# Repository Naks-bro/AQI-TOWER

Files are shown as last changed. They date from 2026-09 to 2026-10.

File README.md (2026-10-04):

# AQI Tower

Latest parallel engineering batch: [concrete results and one-command verification](reports/prototype_d01/batch_summary/README.md). New seal-tolerance and cabinet-joint demand tools, electrical startup/voltage/fault screens, current28-line parts register, and independent handoff audit.18 new synthetic tests pass; no seal, structure, rated circuit or physical performance approval inferred. Use the workbook's **Current combined parts** tab rather than the preserved historical parts list.

AQI Tower is a student engineering project developing a fan-and-filter air cleaner. We are preparing a small indoor prototype before investigating a larger outdoor cylindrical tower.

**Current stage:** internal engineering review. **Physical prototypes built: 0.** The design still needs mechanical and electrical release before construction.

Latest mechanical calculation: [mass and stability supplement](reports/prototype_d01/mechanical_package/MASS_STABILITY_REVIEW.md). Actual guard-hole drawings and published fan weights give a **12.61 kg partial assumed assembly**, not finished tower weight. Filters, feet, seals and controls remain unweighed; no stability approval. Includes reproducible calculations and six synthetic tests.

Latest electrical calculation: [four-page power and wiring supplement](reports/prototype_d01/electrical_package/AQI_D01_POWER_AND_WIRING_SUPPLEMENT.pdf). OEM connector-level reference, verified fan pin functions, 20 load and 36 conditional wire-drop scenarios; ten synthetic tests. Rated restart/protection, actual conductor/fuse selection and enclosure remain open. Do not energize the incomplete circuit.

Implemented ordinary-control candidate: [Opta bench drawing](reports/prototype_d01/electrical_package/AQI_D01_OPTA_BENCH_REVIEW.pdf) and [C++ firmware / source evidence](firmware/d01_opta_review/README.md).1,041 host assertions pass; default firmware also compiles for the real Opta target using official core4.6.0 / CLI1.5.1. [Reproducible board-build evidence](reports/prototype_d01/electrical_package/OPTA_BOARD_BUILD.json). Hardware testing NOT DONE. Relay outputs disabled by default. Not a protective controller or released fan wiring; PR1 remains open. Separate external-box and fuse-coordination screens included in the technical ZIP.

## See the current design

Current control-module fit: [E05 layout/input drawing](reports/prototype_d01/electrical_package/control_module/D01_E05_LID_CONTROLS_REVIEW.pdf) and [editable CAD/evidence](reports/prototype_d01/electrical_package/control_module/README.md). E04's assumed wire-space conflicts are closed by rearrangement, without shrinking reservations. Actual button stack/contact ratings, cables, mounting and rated protection remain unfinished. [Current build decision](reports/prototype_d01/electrical_package/control_module/D01_CURRENT_BUILD_DECISION.pdf) consolidates five remaining release gates. Earlier E03/E04 preserved; no drilling/wiring/build release.

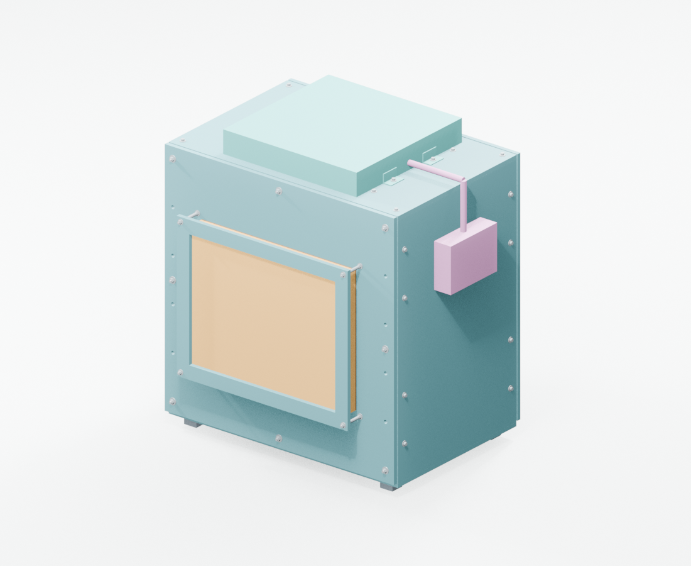
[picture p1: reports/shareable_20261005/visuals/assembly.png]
Current D01 R03M assembly rendered in Blender


*Blender rendering imported from the actual 493-object R03M CAD assembly, not a photograph. Purple parts reserve control/cable space; electrical hardware and protected cable entry are unfinished. The guard faces are solid CAD envelopes: the proposed perforations are not meshed.*

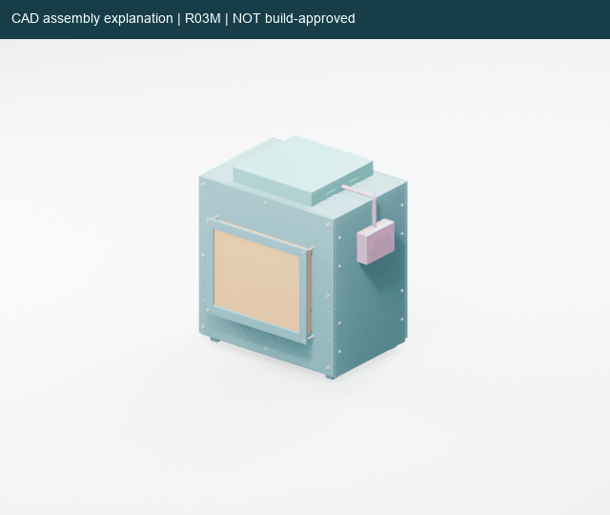
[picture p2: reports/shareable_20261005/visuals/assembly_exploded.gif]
Animated exploded view of the actual CAD assembly


*The exploded view shows how the cabinet, filters, fan plate, guards and hardware fit together. It is a design-review view; welds, threads, tolerances, strength and sealing still need assessment.*

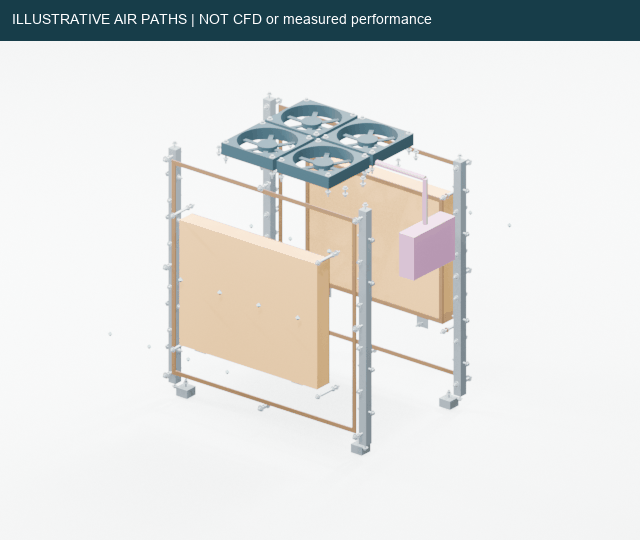
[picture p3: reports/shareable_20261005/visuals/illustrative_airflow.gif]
Illustrative air paths through a cutaway of the prototype


*Hand-authored air markers explain the intended path. This animation is NOT CFD, measured airflow or proof of cleaning. Existing historical CFD remains separately labelled in the technical report.*

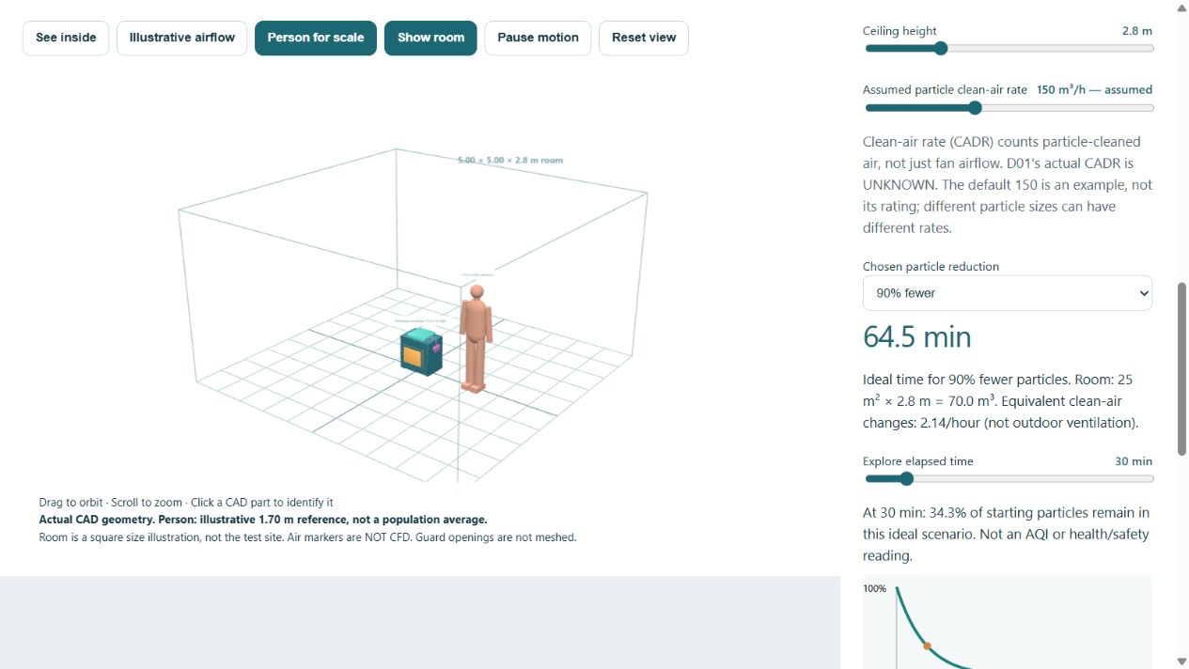
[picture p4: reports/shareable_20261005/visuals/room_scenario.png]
Adjustable room with scale person and assumed particle-cleaning scenario


*The viewer includes a 1.70 m illustrative person and adjustable room area/ceiling height, assumed particle clean-air rate, reduction goal and time. The model predicts ideal particle decay under explicit assumptions, NOT actual D01 performance or safe occupancy. Actual CADR remains unknown. See [room model basis](reports/shareable_20261005/technical/ROOM_MODEL_BASIS.md).*

## Start here

| Reader | Open first |
| --- | --- |
| Stakeholder or new team member | [8-page Executive Summary + Comprehensive Report](reports/shareable_20261005/stakeholder/AQI_TOWER_STAKEHOLDER_REPORT.pdf) or [complete stakeholder ZIP](reports/shareable_20261005/AQI_TOWER_STAKEHOLDER_BUNDLE.zip) |
| Mechanical or electrical engineer | [56-page consolidated technical handoff](reports/shareable_20261005/technical/AQI_TOWER_TECHNICAL_HANDOFF.pdf): current decisions/layout first, preserved evidence afterwards; or [complete technical ZIP](reports/shareable_20261005/AQI_TOWER_TECHNICAL_BUNDLE.zip) |
| Person budgeting the build | [Funding workbook](reports/shareable_20261005/stakeholder/STAKEHOLDER_FUNDING.xlsx); prices and stock remain unknown until quoted |
| Engineer recording decisions | [Technical review workbook](reports/shareable_20261005/technical/TECHNICAL_REVIEW.xlsx), including parts, release, pressure and hardware sheets |
| Anyone exploring the design | [Offline 3D viewer](reports/shareable_20261005/AQI_TOWER_3D_REVIEW.html), with Simple and Technical views, cutaway, part inspection and explosion controls; download and open in a WebGL browser |
| Blender user | [Editable CAD-derived presentation](reports/shareable_20261005/visuals/AQI_R03M_REVIEW.blend), not a manufacturing model |

**The shareable delivery, dated 5 October 2026, preserves IH02 / mechanical R03M evidence and adds current calculation supplements.** The technical PDF preserves the [41-page IH02 reference](reports/prototype_d01/internal_handoff_20261005/03_ENGINEERING_DRAWINGS_AND_REVIEW.pdf) after a five-page introduction, followed by the four-page E01 electrical supplement. See [delivery instructions](reports/shareable_20261005/README.md). Older R00/R01/R02 handoffs and full-size tower studies remain historical evidence; do not combine their filter, fan, wiring or drilling assumptions with this prototype. This is an engineering-review update, not a build release.

## How the first prototype works

Two removable particle filters feed a shared chamber. Four fans move air through it and out through the top guard. The filters are parallel branches, not successive filtration stages.

```mermaid
flowchart LR
    A[Room air] --> B[Filter branch 1]
    A --> C[Filter branch 2]
    B --> D[Sealed shared chamber]
    C --> D
    D --> E[Four parallel fans]
    E --> F[Guarded outlet]
```

The current concept uses four **ARCTIC P14 Max ACFAN00287A** fans and two experimental **IKEA STARKVIND 104.633.30** filter envelopes. IKEA specifies these replacement filters for its STARKVIND appliances; our custom integration has not been endorsed or validated by IKEA. The completed device has no verified HEPA classification.

An external **12 V Noctua power adapter** and OEM fan controller/hub form the electrical reference. Rated protection, isolation, enclosure and harness details remain open. Read the [electrical review](reports/prototype_d01/electrical_package/README.md) before using any schematic.

## What the evidence establishes

| Evidence | What we can say |
| --- | --- |
| CAD and drawings | An integrated assembly, exploded view, panel layouts and proposed hardware exist. Nominal fit checks do not establish manufacturing tolerances, strength or safe access. |
| Fan and pressure calculations | At an assumed 300 m³/h total, the current K1 scenario leaves about **14.32 Pa per filter**. This is conditional headroom under unverified loss assumptions, not actual flow or measured filter resistance. |
| Analysis software | Arithmetic and abstract control checks run. They do not certify hardware or establish physical performance. |
| Physical tests | No complete prototype has been built or measured in the reviewed project records. |
| Future outdoor zones | Bubble radius, removal percentage and tower spacing remain unproven. Indoor results cannot establish outdoor coverage. |

The historical sealed-filter CFD predicted approximately 1,332 m³/h for a different tower geometry and was partial/nonconverged. It does not validate D01. Carbon adsorption, solar assistance and outdoor deployment remain separate development work.

## Intended targets and room sizing

The first prototype aims to reduce airborne particles such as dust and fine smoke particles (PM2.5/PM10), not smoke gases. Actual particle capture and room reduction are unmeasured. No CO₂/CO, VOC/odour, bacteria/virus-control or health-protection performance is established. Filtration does not replace ventilation and source control.

The viewer's example 25 m² room × 2.8 m ceiling has 70 m³ of air. At **assumed**, not measured, 150 m³/h particle-cleaned flow, the ideal 90% reduction time is 64.5 min. A 90% goal in 30 min instead requires 322.4 m³/h effective clean air. Even perfect capture at the **assumed 300 m³/h airflow** screening point cannot meet that target. This calculation helps choose realistic test requirements; it does not establish a room rating. Sources and no-source/perfect-mixing limitations are in [the model basis](reports/shareable_20261005/technical/ROOM_MODEL_BASIS.md).

## What remains before building

- Confirm actual filter resistance, frame tolerances and seal behaviour.
- Finish guard strength/access, cabinet joints, stability and service details.
- Complete rated electrical protection, isolation, enclosure and wiring.
- Resolve cable dimensions requested from ARCTIC and Noctua; [enquiries are sent](docs/build/OEM_CABLE_ENQUIRIES.md).
- Agree the indoor test site and acceptance targets, obtain real quotes, then release parts and fabrication.
- Assemble, inspect, commission and measure airflow, pressure, particles, noise and power.

Internal mechanical and electrical review can proceed while manufacturer replies are pending. Use the [current release register](reports/prototype_d01/internal_handoff_20261005/REVIEW_AND_RELEASE_REGISTER.csv) to record decisions and supporting evidence.

## Repository map

| Location | Purpose |
| --- | --- |
| [Current handoff](reports/prototype_d01/internal_handoff_20261005/START_HERE.md) | Coordinated team package and current tools |
| [Mechanical package](reports/prototype_d01/mechanical_package/README.md) | Base assembly, drawings, guards, fasteners, seals and service evidence |
| [Harness study](reports/prototype_d01/mechanical_package/harness_detail/README.md) | Cable reservations and unresolved entry details |
| [Electrical package](reports/prototype_d01/electrical_package/README.md) | OEM reference chain, power budget and protective-control decisions |
| [Validation package](reports/prototype_d01/validation_package/README.md) | Physical-test preparation and corrected analysis instructions |
| [Project status](memory/project_status.md) | Dated continuation record |
| [Build starting point](docs/build/START_HERE.md) | Current and historical build context |
| [Project overview](docs/PROJECT_OVERVIEW.md) | Purpose and development phases |
| [Requirements](requirements/REQUIREMENTS.md) | Engineering requirements and assumptions |
| [Environment](docs/ENVIRONMENT.md) | Recorded computer and software setup |
| `cad/`, `cfd/`, `data/`, `results/` | Historical models, solver inputs, source data and curated results |
| `scripts/` | Geometry generation, analysis, monitoring and report builders |
| `threejs/` | Browser-based engineering viewer |

## Getting started

```bash
git clone https://github.com/Naks-bro/AQI-TOWER.git
cd AQI-TOWER
```

For documentation, start with the PDFs above. FreeCAD opens the [current native assembly](reports/prototype_d01/mechanical_package/D01_R03M_ASSEMBLY.FCStd); a [STEP export](reports/prototype_d01/mechanical_package/D01_R03M_ASSEMBLY.step) is also available. These files are for review.

Current analysis checks use Python 3 and the standard library:

```bash
python scripts/analysis/d01_validation.py
python scripts/analysis/d01_guard_bending.py
python scripts/analysis/d01_control_acceptance.py
python -m unittest discover -s scripts/analysis -p test_d01_current_filter_screen.py -v
python scripts/maintenance/check_readme_links.py
python scripts/maintenance/check_shareable_delivery.py
```

Read [tool usage](reports/prototype_d01/internal_handoff_20261005/TOOL_USAGE.md) before analysing measurements. Keep raw observations unchanged, identify calibration/source references, and label synthetic fixtures clearly. Rebuilding CAD or PDF reports requires additional software documented with the relevant builder; the small checks above do not.

For the new presentation viewer, extract either bundle and open `AQI_TOWER_3D_REVIEW.html`. No installation, server or internet is required; WebGL is required. GitHub previews do not run the HTML application. Both audiences can use the same model with different explanations.

To run the historical GEO_C engineering viewer (different geometry):

```bash
cd threejs
npm ci
npm run dev
```

OpenFOAM/ParaView workflows belong to their documented historical studies. Do not treat running an old solver case as validation of the current physical assembly.

## Contributing

Use one branch and PR for one meaningful change. Describe the problem, affected revision, checks performed and remaining limitations. Follow the [PR template](.github/pull_request_template.md), update [CHANGELOG.md](CHANGELOG.md), and update this README when the current handoff, status or onboarding workflow changes.

Keep facts, assumptions, digital predictions and physical measurements distinct. Preserve historical files and raw observations. Do not commit credentials, private correspondence, generated solver time directories, `node_modules` or local inspection screenshots. Current downloadable handoff/bundle ZIPs are intentionally tracked; redundant old report ZIPs remain local.

## What is on GitHub

Project sources, curated engineering evidence, current CAD/drawings, results, reports, workbooks, final visuals and downloadable bundles are tracked. This is not a byte-for-byte mirror of every local file. Approximately 1.75 GB of generated raw solver fields/meshes/logs, dependencies, scratch work and old recordings remain local; nothing was deleted. The [coverage inventory](reports/shareable_20261005/GITHUB_COVERAGE.csv) records excluded categories and readable sizes, including inaccessible WSL links. Existing source cases and curated CFD results remain preserved in the repository.

**AQI Tower is a working name.** The final device name has not been selected. This repository does not claim verified outdoor coverage or patentability.

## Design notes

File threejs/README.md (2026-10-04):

# AQI Tower — Engineering Viewer T3

## Current prototype presentation

The current D01 R03M prototype has a separate [offline dual-mode viewer](../reports/shareable_20261005/AQI_TOWER_3D_REVIEW.html). Download/open it locally, or extract either [shareable bundle](../reports/shareable_20261005/README.md). It uses the actual 493 CAD objects and provides Simple/Technical modes, cutaway, explosion, part inspection and explicitly illustrative air markers. A 1.70 m reference person and adjustable square room show scale; area/ceiling/assumed-CADR/time controls and reduction goals drive an ideal particle-decay chart. CADR is UNKNOWN for D01; defaults are examples. It is not a CFD solver, medical-clearance tool or manufacturing model. Test arithmetic with `node test_room_scenario.mjs` from this folder. See the [source/assumption basis](../reports/shareable_20261005/technical/ROOM_MODEL_BASIS.md).

Sources are `src/presentation.js` and `presentation.template.html`. Build its bundled JS with the existing esbuild dependency, then run `scripts/reports/build_shareable_delivery.py` using the documented ReportLab/openpyxl/Pillow/pypdf/pypdfium2 environment. The report builder also requires the existing Blender renders and current IH02 evidence. Do not treat a presentation rebuild as an engineering release.

## Historical GEO_C viewer

Interactive browser-based 3D engineering viewer for the AQI Tower GEO_C concept.
T3 adds real CFD scalar field visualization — velocity magnitude and static pressure sampled on 2-D planes from existing solved OpenFOAM cases.

**PARALLEL VISUALISATION TRACK.** This viewer is an engineering representation only. CFD field planes are post-processed from existing solved fields; they are NOT raw CFD data and are NOT physically validated. All quantities are labeled SIMULATION ONLY.

## Technology

Vite + Three.js + JavaScript ES modules. No React, no TypeScript.

## Quick start

```bash
cd threejs
npm install
npm run dev       # dev server at http://localhost:5173
npm run build     # production build → dist/
```

## File structure

```
threejs/
├── data/
│   ├── towerConfig.js          # GEO_C geometry + CFD result numbers
│   ├── engineeringStatus.js    # Status system definitions
│   ├── cases.js                # Case metadata registry (exact values from JSON sources)
│   └── particleData.js         # Phase 12B particle data, seed positions, schematic terminals
├── src/
│   ├── main.js                 # Entry point: scene, camera, controls, UI wiring, mode switching
│   ├── scene/
│   │   ├── createTower.js      # 3D geometry for all tower zones
│   │   ├── createAirflow.js    # Schematic airflow arrows
│   │   └── createParticles.js  # Particle geometry (real or schematic), filters
│   └── ui/
│       ├── infoPanel.js        # Click-to-select info panel
│       ├── layerControls.js    # Layer toggle panel
│       ├── particlePanel.js    # Particle size/outcome filter panel + Phase 12B stats
│       ├── provenancePanel.js  # Expandable data provenance panel
│       └── modeSelector.js     # ARCHITECTURE / PARTICLE / CFD SUMMARY mode tabs
├── tools/
│   ├── export_particle_trajectories.py  # Read-only pvpython export (T2)
│   └── cfd/
│       └── export_scalar_planes.py      # Read-only pvpython CFD plane export (T3)
├── public/
│   └── data/
│       ├── particleTrajectories.json    # Drop here for real particle mode (T2)
│       └── cfd/                         # CFD plane JSON files (T3, generated by export script)
├── index.html
├── vite.config.js
└── package.json
```

## Viewer modes

| Mode | Panel shown | What it shows |
|---|---|---|
| ARCHITECTURE | Layer toggles, explode slider | Tower geometry, schematic airflow, click-to-select |
| PARTICLE | Particle panel | Phase 12B seed/terminal geometry; real trajectories if exported |
| CFD SUMMARY | CFD overlay | Exact case metrics from GEO_C and CASE_M_SEALED JSON files |
| CFD FIELD | CFD field panel | Real velocity/pressure planes from solved OpenFOAM fields |

In CFD FIELD mode, the explode slider is disabled — spatial CFD planes cannot be offset from their original coordinates without becoming physically misleading.

## T3 — CFD scalar field visualization

### CFD field audit

| Case | Path | Final timestep | Status | Cells | U range | p range (Pa) |
|---|---|---|---|---|---|---|
| GEO_C | cfd/GEO_C | 926 | CONVERGED | 63,780 | 0.001–5.620 m/s | −20.43–−0.06 Pa |
| GEO_C_CONFIRM | cfd/GEO_C_CONFIRM | 926 | CONVERGED | 63,780 | 0.001–5.620 m/s | −20.43–−0.06 Pa |
| CASE_M_SEALED | cfd/FILTER_H13/CASE_M_SEALED | 5000 | PARTIALLY CONVERGED | 67,838 | 0.001–5.268 m/s | −128.92–−0.17 Pa |

GEO_C and GEO_C_CONFIRM have identical fields — confirmed deterministic reproducibility. CASE_M_SEALED has a much larger pressure range due to the H13 filter resistance (ΔP ≈ 111 Pa).

### Pressure unit interpretation

OpenFOAM `p` field has dimensions `[0 2 -2 0 0 0 0]` = m²/s² = **kinematic pressure** (p/ρ, used by incompressible RANS solvers). All values in solver units are negative (gauge relative to outlet reference).

Conversion: **P_static (Pa) = p_kinematic × ρ** where ρ = 1.20 kg/m³ (from `constant/physicalProperties`).

The export script applies this conversion and marks the field as `DERIVED FROM CFD PRESSURE FIELD`. Values are gauge pressure relative to the solver reference. Do not interpret absolute values as total pressure.

### Planes exported

| Plane ID | Normal | Position | Domain covered |
|---|---|---|---|
| `longitudinal` | y | y = 0.400 m | Full flow path from inlet to riser top |
| `filter_xsec` | x | x = 0.305 m ± 20 mm slab | Filter face / STAGE_03 cross-section |

The longitudinal plane at y = 0.400 m is the exact center of the flow domain (domain depth y ∈ [0.10, 0.70] m). This is the same plane used in the existing phase10b_visualize.py. The cross-section at x = 0.305 m corresponds to STAGE_03_mid in GEO_C metrics and the actual filter baffle position in CASE_M_SEALED.

### Export pipeline

**Dependency:** ParaView pvpython (installed in WSL)

**Tool:** Uses `OpenFOAMReader` + `vtkCellCenters` + `scipy.interpolate.griddata` (same pattern as existing `scripts/simulation/phase10b_visualize.py`).

**Grid resolution:**
- Longitudinal: 100 × 130 ≈ 13,000 grid points per field (domain: x∈[0, 0.71] m, z∈[0.14, 1.86] m)
- Filter cross-section: 65 × 75 ≈ 4,875 grid points (domain: y∈[0.09, 0.71] m, z∈[0.14, 0.88] m)

**Run from AQI-TOWER root (WSL):**
```bash
pvpython --force-offscreen-rendering threejs/tools/cfd/export_scalar_planes.py
```

**Output:** 12 JSON files + `cfd_index.json` in `threejs/public/data/cfd/`. Total size ≈ 650 KB.

### JSON format

Each export file contains:
```json
{
  "schema_version": 1,
  "case_id":        "GEO_C",
  "case_path":      "cfd/GEO_C",
  "source_timestep": "926",
  "field":          "U_MAGNITUDE",
  "field_description": "Velocity magnitude |U|",
  "derivation":     "DERIVED FROM CFD VELOCITY FIELD: |U| = sqrt(Ux² + Uy² + Uz²)",
  "units":          "m/s",
  "plane":          "longitudinal",
  "grid":           { "type": "longitudinal", "n_axis1": 100, "n_axis2": 130, ... },
  "data_min":       0.016,
  "data_max":       5.211,
  "n_valid":        10102,
  "n_total":        13000,
  "values":         [...],   // null where outside domain
  "convergence_status":  "CONVERGED",
  "validation_status":   "SIMULATION ONLY — NOT PHYSICALLY VALIDATED",
  "provenance":     { ... }
}
```

### Colormap

Six-stop turbo approximation: dark purple → cyan → green → yellow → orange → dark red. Perceptually suitable for CFD scalar visualization. Higher value = higher scalar only — no danger interpretation.

### Browser visualization limitations

- Cells are sampled on a grid; outside-domain cells are blank (null)
- Visual interpolation between grid points is for rendering only — not additional CFD resolution
- The planes are 2-D slices; no 3-D volume rendering
- Interpolation from scattered cell centers uses `scipy.griddata` linear method
- No streamline rendering (streamlines not exported; would require separate pipeline)

## Particle trajectory data

Phase 12B (`scripts/simulation/phase12b_particle_tracking.py`) does **not** store path coordinates — only terminal positions are tracked in-memory and discarded after the run. Only summary statistics exist on disk in `results/PARTICLE_CFD/particle_arrival_fractions.json`.

**Viewer behaviour:**
- On startup, the viewer attempts `fetch('./data/particleTrajectories.json')`
- If found: **REAL TRAJECTORY DATA LOADED** — actual coordinates from the export tool
- If not found: **SCHEMATIC MODE** — exact seed grid positions from script parameters; terminal positions geometry-derived using seeded PRNG (reproducible)

**Generating real trajectories:**

```bash
# WSL/Linux with ParaView pvpython
pvpython --force-offscreen-rendering threejs/tools/export_particle_trajectories.py
# Output: threejs/public/data/particleTrajectories.json (~2–3 MB)
```

The export tool replicates Phase 12B integration (equilibrium-slip Euler, dt=0.004 s, frozen CASE_M_SEALED field) and stores path waypoints every 25 steps (≈0.1 s intervals, max 60 points per particle).

**Trajectory JSON format:**
```json
{
  "meta": { "version": 1, "n_seeds": 224, "n_sizes": 4, "store_interval_steps": 25 },
  "sizes": {
    "0p3um": {
      "d_m": 3e-7,
      "particles": [
        { "outcome": "FILTER_ARRIVAL", "path": [[x0,y0,z0], [x1,y1,z1], ...] }
      ]
    }
  }
}
```
Coordinates are in Three.js space (x=flow−0.350, y=CAD_z−0.925, z=CAD_y−0.400).

## CFD streamlines

No streamline export files exist in this repository. The schematic airflow arrows in ARCHITECTURE mode follow the GEO_C flow topology but are **SCHEMATIC — NOT CFD FIELD DATA**. The provenance panel labels them clearly.

## Engineering vs schematic distinction

| Colour | Type | Meaning |
|---|---|---|
| Blue (#4a9eff) | ENGINEERING / CAD | Geometry from CAD file or physical product spec |
| Teal (#2ad4a0) | CFD SIMULATED | Value from CFD simulation result |
| Amber (#c07830) | SCHEMATIC / PROVISIONAL | Placeholder; design not frozen |
| Purple (#a050c0) | CONCEPT ONLY | No engineering basis; feasibility undecided |

## Data sources (T2)

| Data | Source file | Status |
|---|---|---|
| GEO_C flow rate, fan dP | `results/GEOMETRY_OPTIMIZATION/GEO_C/metrics.json` | Exact values in `data/cases.js` |
| CASE_M_SEALED filter ΔP, face velocity, bypass | `results/FILTER_H13/bypass_analysis_sealed.json` | Exact values in `data/cases.js` |
| Phase 12B particle counts | `results/PARTICLE_CFD/particle_arrival_fractions.json` | Exact values in `data/particleData.js` |
| Phase 12B trajectories | NOT EXPORTED | Run `tools/export_particle_trajectories.py` |
| CFD streamlines | NOT EXPORTED | No export tool exists; schematic arrows used |

## CFD summary (from exact JSON values)

All values from `results/FILTER_H13/bypass_analysis_sealed.json` and `results/PARTICLE_CFD/particle_arrival_fractions.json`. PARTIAL NON-CONVERGED RANS. Not validated on physical hardware.

| Parameter | Exact value | Source |
|---|---|---|
| Airflow (GEO_C, 926 iter) | 1496.055 m³/h | GEO_C/metrics.json |
| Airflow (CASE_M_SEALED, 5000 iter) | 1332.205 m³/h | bypass_analysis_sealed.json |
| Filter ΔP (CASE_M_SEALED) | 111.181 Pa | bypass_analysis_sealed.json |
| HEPA face velocity (mean) | 1.0525 m/s | bypass_analysis_sealed.json |
| Bypass fraction (sealed) | 9.997×10⁻¹⁰ | bypass_analysis_sealed.json |
| Particle 0.3 µm — filter arrival | 139/224 = 62.1% | particle_arrival_fractions.json |
| Particle 10 µm — filter arrival | 137/224 = 61.2% | particle_arrival_fractions.json |

**FILTER ARRIVAL ≠ FILTER CAPTURE EFFICIENCY.**
**OUTLET = 0 does NOT prove downstream capture.**

## Known limitations

- Phase 12B trajectories not exported; viewer shows schematic paths until pvpython export is run
- No real CFD streamlines exist; ARCHITECTURE mode airflow is schematic topology only
- GEO_C RANS cases did not fully converge; all CFD quantities are screening-level estimates
- No turbulent dispersion in Phase 12B particle model (equilibrium-slip Euler only)
- η(d_p) filter capture efficiency is not available — only arrival fractions are displayed

## Geometry source

GEO_C CAD parameters from `cad/parametric/PHASE8_GEOMETRY_AUDIT.json`:
- `riser_inner_x_mm`: 260 mm
- `riser_top_z_mm`: 1850 mm
- Two-step turning chamber: x=[500,590] and x=[590,690] mm

## T1 acceptance status

| Criterion | Status |
|---|---|
| Vite + Three.js + ES modules | PASS |
| GEO_C tower geometry | PASS |
| OrbitControls | PASS |
| Transparent enclosure | PASS |
| HEPA filter zone (ENGINEERING) | PASS |
| Carbon stage (SCHEMATIC/PROVISIONAL) | PASS |
| Water stage (CONCEPT) | PASS |
| Fan KVO 250 (SCHEMATIC) | PASS |
| Component selection + info panel | PASS |
| Engineering-status labels in info panel | PASS |
| Layer toggles | PASS |
| Explode view | PASS |
| Schematic airflow arrows | PASS |
| CFD summary panel | PASS |
| Dark engineering UI | PASS |
| ENGINEERING vs SCHEMATIC distinction | PASS |
| Data in towerConfig.js / engineeringStatus.js | PASS |
| No modification of cad/, cfd/, results/ | PASS |
| npm install + build succeeds | PASS |

## T3 acceptance status

| Requirement | Status |
|---|---|
| T1 preserved | PASS |
| T2 preserved | PASS |
| Existing CFD fields audited (U, p, bounds, convergence) | PASS |
| No solver rerun | PASS — export reads existing solved fields only |
| Velocity magnitude exported (|U| = sqrt(Ux²+Uy²+Uz²)) | PASS |
| Pressure exported (P = p_kin × ρ, Pa gauge) | PASS |
| Longitudinal plane (y=0.400 m) | PASS |
| Cross-section plane (x=0.305 m ± 20 mm) | PASS |
| Real CFD FIELD mode in viewer | PASS |
| Case selector (GEO_C / GEO_C_CONFIRM / CASE_M_SEALED) | PASS |
| Field selector (U magnitude / P static) | PASS |
| Plane selector (longitudinal / filter cross-section) | PASS |
| Scientific color legend (turbo colormap) | PASS |
| Units verified (U: m/s; P: Pa gauge) | PASS |
| Pressure semantics verified (kinematic × ρ=1.20 documented) | PASS |
| Provenance panel (case, path, timestep, derivation, note) | PASS |
| Convergence status displayed per case | PASS |
| No fake interpolation claims (VISUAL INTERPOLATION label) | PASS |
| Exploded view disabled in CFD_FIELD with explanation | PASS |
| Schematic airflow hidden in CFD_FIELD | PASS |
| npm run build passes | PASS — 518.21 kB in 3.39 s |
| cad/ modified | NO |
| cfd/ modified | NO |
| results/ modified | NO |
| Existing CFD outputs modified | NO |

## T2 acceptance status

| Requirement | Status |
|---|---|
| T1 fully preserved | PASS |
| Real particle data imported (fetch → real mode) | PASS |
| Schematic mode when real data unavailable | PASS |
| Diameter filter (ALL, 0.3, 1.0, 2.5, 10 µm) | PASS |
| Outcome filter (FILTER_ARRIVAL, FRAME_DEPOSIT, WALL_DEPOSIT) | PASS |
| Particle data provenance in provenance panel | PASS |
| Case metadata registry (data/cases.js, exact JSON values) | PASS |
| GEO_C metadata (exact: 1496.055 m³/h, 926 iter, CONVERGED) | PASS |
| CASE_M_SEALED metadata (exact: 1332.205 m³/h, 111.181 Pa) | PASS |
| Phase 12B particle metadata (exact counts per size/outcome) | PASS |
| Real CFD streamlines: honestly labeled NOT EXPORTED | PASS |
| No fake CFD field visualisation | PASS |
| FILTER ARRIVAL ≠ CAPTURE warning always shown | PASS |
| OUTLET = 0 ≠ downstream capture — always shown | PASS |
| SIMULATION ONLY / NOT PHYSICALLY VALIDATED labels | PASS |
| Read-only trajectory export tool provided | PASS |
| BufferGeometry + Float32Array for particle geometry | PASS |
| Mode selector (ARCHITECTURE / PARTICLE / CFD SUMMARY) | PASS |
| CFD overlay with exact case registry values | PASS |
| Expandable provenance panel | PASS |
| npm run build passes | PASS |
| cad/ modified | NO — not touched |
| cfd/ modified | NO — not touched |
| results/ modified | NO — not touched |
| Existing CFD outputs modified | NO — not touched |

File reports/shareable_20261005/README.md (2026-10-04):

# Shareable AQI Tower delivery

5 October 2026. Two audiences, one unchanged engineering basis: D01 R03M / IH02.

- stakeholder/: 8-page plain-language Executive Summary and Comprehensive Report, room-scenario/funding workbook, offline dual-mode viewer and GIFs.
- technical/: one56-page review: current build decisions/E05 control layout/E02 bench reference first, preserved earlier50-page evidence afterwards; workbook, authoritative CAD/STEP/DXFs, current tools and editable Blender presentation. Current release gates and control placement are included. Not construction release.
- The viewer now includes a1.70 m scale person, adjustable square room, area/height/assumed-CADR/time sliders and an ideal particle-decay chart. Default clean-air rate is an example, not a D01 rating. ROOM_MODEL_BASIS.md gives sources and limits.
- visuals/: actual CAD-derived renders and annotated GIFs. Colour identifies parts; air motion is illustrative, not CFD.
- GITHUB_COVERAGE.csv: excluded generated/dependency/history categories retained locally. GitHub is not an exact mirror of raw solver time folders or dependencies.

Extract either ZIP before opening its HTML. WebGL is required for 3D; PDFs and GIFs remain usable without it. The viewer is offline and includes the Three.js MIT licence. Source build tools are scripts/visualization/ and scripts/reports/build_shareable_delivery.py.

No new physical results or build approval. Exact component/filter data, mechanical/electrical release, quotations, site, fabrication and safe commissioning remain outstanding. No fabricated price or completion date. Final device name not selected.

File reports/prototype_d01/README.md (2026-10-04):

# D01 indoor demonstrator engineering package

**Latest continuation: [R01 attachment and construction details](r01/README.md).** Updated assembly, guard/cabinet/shelf fastenings, eleven revised drilling DXFs and reduced airflow screening for the guard's solid rim. R00 below is preserved; its hole drawings and airflow numbers must not be mixed with R01.

3 October 2026. R00 is a **design-review deliverable, not a fabrication, procurement or energization release**. Physical prototypes built: **0**.

Open **AQI_D01_ENGINEERING_PACKAGE.pdf** first. The first two pages explain the proposal to stakeholders; the remaining pages show the actual assembly, drawings, pressure budget, electrical connection plan, BOM and physical test procedure.

## Recommended route

Build a custom low-voltage indoor particle demonstrator before committing to the large cylindrical tower. Two opposed MERV13 filters and four top-mounted PC fans share a sealed, serviceable panel enclosure. Our work is the mechanical integration, seals, control integration, measurements and validation; it is not an off-the-shelf purifier or a claim of inventing PC-fan filtration.

This is a **recommended reduction in first-demonstrator scope**, not evidence that the larger HEPA tower is ready or that the user has approved procurement. MERV13 is not HEPA. No gas, biochar, water, solar or outdoor cleaning claim is made. The previous full-size tower route is retained, not silently replaced or released.

## Delivered files

- `D01_ASSEMBLY.FCStd` and `D01_EXPLODED.FCStd`: same assembly in native FreeCAD, 73 objects. Regenerated solid features; not a fully constrained production feature tree.
- `D01_ASSEMBLY.step`: vendor-neutral assembly geometry.
- `D01_ASSEMBLY.png` and `D01_EXPLODED.png`: renders from that CAD tessellation. Pleat markings and perforations are visual annotations; CAD filters and guard faces are envelopes. No AI concept rendering or physical photograph.
- `panel_dxf_REVIEW_ONLY/`: eight 1:1 millimetre panel/guard-outline files. No kerf compensation, guard perforation holes, unmodeled screw schedules or attachment flanges. **Do not send directly to a cutter.**
- `panel_geometry.json`: dimension and hole-coordinate data matching the generated panels.
- `D01_BOM.csv`: exact OEM reference products separated from proposed/unresolved hardware and services. No guessed prices or stock claims.
- `pressure_results.json` and `pressure_curves.csv`: reproducible screening and nine arithmetic checks; not physical results.
- `geometry_checks.json`: 435 panel/filter/support pair checks and 1,280 hardware-to-part checks; zero checked positive-volume clashes. Nuts/washers, guard-to-guard overlaps and control reservation excluded; no strength approval.

## What is fixed in this proposal

- Cabinet 550 wide x360 deep, top at580 above floor. Top guard raises height to631. Filter/retainer depth472.90 excluding studs; stud envelope reaches490. External control reservation raises width to590. No outdoor weatherproofing.
- OEM reference filter 495.3 square x44.45 deep. Sealed470 square seat aperture. Retainer550 square with475 aperture and eight5.5 clearance holes per face; minimum retainer hole centre-to-edge20. Seat edge centres minimum11; check plywood bearing and reinforcement with reviewer.
- Two235 x47.45 x9 ledges per filter, separated by20 to clear the bottom centre stud. Filter support does not rely only on gasket friction.
- Side studs: twelve M5x100; centre studs: four M5x80. Sixteen proposed M4x50 fan bolts. These lengths require delivered stack/washer/nut and thread-engagement checks; fasteners are not strength-released.
- Four P14 Max140 square x27 fans;125 mounting pitch and134.2 fan aperture from OEM drawing/template. Native fan rotors are simplified proxies.
- The Noctua NV-PS1 / included NA-AC10 / NA-FC1 / NA-FH1 chain is an OEM-documented combination, with third-party fan compatibility still to check. Four fans nominally1.4A/16.8W versus supply2A/24W; startup and auxiliary loads unmeasured.

## What was actually learned

Existing CAD/CFD and measurement scripts are reusable evidence and tools, but not one released physical machine. The full-size fan does not satisfy every assumed loaded duty point. Repeated outer-casing and closure branches advanced packaging but did not resolve component procurement or electrical release.

D01 trades HEPA and full-size flow for much simpler integration. Screening intersections are376.7,352.1 and308.7m3/h for **assumed** filter-resistance scenarios. They are not a guaranteed interval. The exact S&P filter pressure curve was not obtained; fan curve values are visually digitized. Two filters in parallel each carry half the flow; four parallel fan pressures do not add.

During this turn, review found and corrected narrow retainer ligaments, side-stud length, central-stud/inner-guard interference and lower-stud/shelf interference. Nominal clearance is not the same as a tolerance, load, seal or safety pass.

## Remaining work, specific to this assembly

1. **Obtainable parts:** resolve the P14 Max SKU/revision conflict (current PDF versus older drawing/store identity), stock and delivered manual. Checked Indian listings were out of stock. Confirm a traceable MERV13 filter with matching actual dimensions and pressure curve. India availability of S&P 990303 and the Noctua chain is UNKNOWN. A substitute requires geometry, current and pressure recalculation.
2. **Digital detailing:** complete guard flanges/fixing holes, cleat screw schedule, shelf support detail, top seam/gasket, external enclosure/gland/cable layout, washers/nuts and compression stops as appropriate. The JSON captures R00 inputs, but some construction coordinates are explicit in the generator; changing JSON alone does not update every detail.
3. **Mechanical release:** specify actual plywood, adhesive, fasteners, gasket force/landing and guard sheet; check retainer bending, joint capacity, total mass/centre of gravity, tip/slide resistance and guard reach/deflection. Then inspect dimensions and seals physically.
4. **Electrical release:** confirm actual Indian socket/approved plug adaptation, OEM connector chain, 4-fan startup current, protection and restraint. This chain does NOT implement the existing tower manual-restart/interlock requirement. Either implement a reviewed rated restart-inhibit arrangement or obtain an explicit guarded bench-only exception from the qualified reviewer; do not silently waive it. No unattended operation. Unplug before service and verify all fans stopped.
5. **Physical demonstration:** authorized purchase -> delivery -> local fabrication -> commissioning -> repeated trials with rented/paid instruments. No college lab or optional ENTC friend is assumed. Record total flow, filter pressure, watts, noise and matched room particle-decay data. Low-cost PM readings do not certify HEPA/MERV efficiency.

These are concrete remaining interfaces, not closed gates. No supplier, reviewer or workshop was contacted. No lead time, total budget or completion date is confirmed.

## Evidence and licences

Sources checked3 October2026:

- [ARCTIC manual, 2025 drawing and mounting template](https://support.arctic.de/p14-max). Dimensions140x140x27;125mm pitch. Drawing says ACFAN00287A; current spec sheet associates colour/revision differently. Do not assume an older shop listing resolves this.
- [ARCTIC P14 Max specification and chart](https://www.arctic.de/media/8a/18/01/1710507321/Spec_Sheet_P14_Max_EN.pdf). Digitization is approximate, not an OEM numeric table.
- [S&P MERV filter submittal](https://www.solerpalau-usa.com/documents/Submittal/trc-merv.pdf). Part 990303 is the MERV13 dimensional reference, not evidence of India stock or resistance. The archived file name abbreviates the part number; the full OEM part is 990303.
- [Noctua NV-PS1](https://www.noctua.at/en/products/nv-ps1), [specifications](https://www.noctua.at/en/products/nv-ps1/specifications), [NA-FH1](https://www.noctua.at/en/products/na-fh1/specifications), [NA-FC1 total-current FAQ](https://www.noctua.at/en/support/faqs/how-many-fans-can-i-connect-to-the-na-fc1-controller). OEM system ratings do not certify our assembled purifier.
- [MDComputers P14 Max listing](https://mdcomputers.in/product/arctic-p14-max-140mm-case-fan-acfan00287a): out of stock when checked, not a quotation. No claimed India-wide unavailability.
- [Tempest Brisa open-source build](https://github.com/obife29/Tempest-Brisa-Open-Source), [CC0 licence](https://github.com/obife29/Tempest-Brisa-Open-Source/blob/main/LICENSE). A DXF and licence are archived as a precedent, not reused as this CAD or treated as independent performance proof. Repository credits Maria Boavida/OMA, Shawn Santos/Ar Limpo Lisboa, Florian Festi/Boxes.py and Naomi Wu/Nukit. Credit retained; no patentability or trademark-rights claim.

Archived references are under `data/prototype_d01/sources`. `ARCTIC_P14_Max_PQ.pdf` is a failed HTML download despite its extension; it is **not evidence**. Use the valid `ARCTIC_P14_Max_Spec.pdf` chart. `MeanWell_GST60A.pdf` was screened but is not selected. Do not treat OEM documents as open-source CAD licences. The downloaded Brisa reference is the only archived construction precedent carrying the inspected CC0 licence.

## Reproduce inside this workspace

```powershell
& 'D:\Applications\FreeCAD 1.1.3\bin\python.exe' scripts/geometry/build_d01.py
& 'C:\Users\G15 5530\.cache\codex-runtimes\codex-primary-runtime\dependencies\python\python.exe' scripts/analysis/d01_pressure.py
& 'C:\Users\G15 5530\.cache\codex-runtimes\codex-primary-runtime\dependencies\python\python.exe' scripts/reports/build_d01_delivery.py
```

No new software was installed. Historical documents and models remain untouched except for navigation/status additions.

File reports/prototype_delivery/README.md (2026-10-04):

# AQI Tower stakeholder demonstration package

Created 3 October 2026. Share the PDF; open the HTML in a browser for an offline presentation. Keep PDF and HTML together so its report link works. Existing stakeholder report is preserved separately.

- `AQI_TOWER_PROTOTYPE_STAKEHOLDER_BRIEF.pdf`: six-page plain-language proposal with original functional diagrams, actual project viewer screenshot, public references, completed digital work and a funding request. No meetings page or student-led cover label.
- `PROTOTYPE_DEMO.html`: clickable layer explanations, illustrative flow animation and future network concept. No dependencies, live sensor data, new CFD or physical performance claims.
- `qa_*`: internal render/screenshot checks, not stakeholder deliverables.

The optional commercial-appliance reference demonstration is proposed for team approval. It is NOT an AQI Tower prototype or substitute proof of the custom tower. No device selected/purchased. EPA published MERV 13 precedent is not a HEPA design, India electrical approval, freely licensed third-party CAD or transferred performance result. Diagrams are our original explanation drawings, not copied manufacturer illustrations.

Build source: `scripts/reports/build_prototype_brief.py`. Run with the bundled workspace Python containing reportlab and pypdfium2. It regenerates this PDF and QA page renders; it does not modify existing models/results. Every PDF page was visually reviewed. Browser checks passed for component selection, network toggle, animation pause, absence of script errors and mobile overflow; desktop/mobile screenshots reviewed. These are presentation checks, not engineering validation.

## Short presentation script

We are developing a tower that draws air through dust filters and returns filtered air. We already have computer airflow studies, packaging models and measurement tools. We have not built or physically tested the tower yet. We are asking for support to assemble one safe indoor prototype using standard components and a local workshop, then measure what it actually does. The outdoor chain of cleaner-air zones is our future research goal, not a proven result. We can show the digital model today and, if approved, arrange a separately labelled reference-appliance demonstration while developing our own core.

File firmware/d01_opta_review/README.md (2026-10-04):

# D01 Opta ordinary-control bench candidate

**Not safety-rated. Not released for wiring, fan operation or energization.**

This is implemented C++ ordinary START/STOP/RESET logic on a specific proposed controller, Arduino Opta Lite AFX00003. It is not a replacement for the open PR1 protective circuit. No new controller has been purchased or installed. On 5 October 2026, the user authorized the isolated Arduino CLI/core installation: the default sketch compiles for the real Opta board target. Flashing and physical tests are NOT DONE.

## What the code does

- Boot, loss of the sensed source and power restoration clear RUN; held START cannot start it until released and pressed again.
- STOP has priority. A missing bench permission latches TRIP; recovery needs RESET and then a separate fresh START.
- START/RESET have an ASSUMED25 ms debounce; STOP and permission are not delayed by that debounce. Polling is nominal5 ms. A returned scan gap over ASSUMED100 ms latches an inhibit; a frozen CPU is NOT protected by this check.
- By default **all four relay commands stay LOW**, even when RUN REQUESTED is true. LEDs show requests only. The shipped sketch must never drive a fan.
- `AQI_BENCH_LAMP_OUTPUT_ENABLED=1` is solely for a reviewed, fused, low-voltage dummy-load bench. It is NOT permission to connect the tower. Output1 contact minimum-load constraints apply to the chosen dummy lamp.
- No networking, retained RUN bit, remote START or blocking wait for a USB connection.

## OEM-supported proposed input mapping

| Terminal | Arduino identifier | Proposed ordinary bench function |
|---|---|---|
| I1 | A0 | START, normally-open momentary contact |
| I2 | A1 | STOP loop, normally closed / HIGH when healthy |
| I3 | A2 | RESET, normally-open momentary contact |
| I4 | A3 | Bench permission contact; NOT a safety input |
| I5 | A4 | Unswitched12 V source-presence indication, DIGITAL mode only |
| Output1 | D0 | Disabled by default; proposed dummy-lamp contact only |

OEM terminals use their printed `+`, `-`, `I1`–`I8` and numbered output-pair labels. We do not invent COM/NO terminal identifiers. Determine actual polarity, compatible harness, source-side protection and physical terminations from the drawing and qualified bench review. Never connect12 V to an analog-mode input; OEM analog range is0–10 V, while digital range is0–24 V. A digital HIGH threshold is not precision undervoltage protection. No fan tach inputs are connected here.

Run `python scripts/analysis/test_d01_opta_host.py` from the repository or packaged engineering root with an already-installed host `g++`. It compiles the actual core and sketch against a clearly labelled GPIO shim and writes `OPTA_HOST_CHECKS.json`. This is not an Opta target build. The separate real-board build is recorded in `OPTA_BOARD_BUILD.json`; review and hardware tests are still required before bench use.

Board-build preparation: desktop tests and their Arduino shim live outside the sketch in `firmware/tests/d01_opta/`. Arduino otherwise compiles sketch-root `.cpp` files, which would bring in the test `main()` and duplicate sketch definitions. The host runner checks this layout.

DETECTED build toolchain: Arduino CLI 1.5.1 and official `arduino:mbed_opta@4.6.0`, installed only in Git-ignored `.tools/arduino/`. CLI archive SHA256 was checked against the official release checksums. No system PATH changes or hardware uploads. The default `arduino:mbed_opta:opta` target (M7 / 2 MB M7 flash split / no signing) compiled with all compiler warnings enabled: 128,464 bytes program storage and 59,232 bytes dynamic memory, no warnings reported. This proves compilation/linking, not correct operation on hardware. The dummy-lamp-enabled variant is NOT compiled or released by this check.

Reproduce on this computer: `python scripts/analysis/compile_d01_opta.py`. The script never installs or uploads; it uses the isolated existing toolchain. On another computer, install the same official versions and configure the local `.tools/arduino/arduino-cli.yaml` directories first. Evidence: [board build record](../../reports/prototype_d01/electrical_package/OPTA_BOARD_BUILD.json). Binaries/toolchain remain local, not included in the technical ZIP. Official [CLI installation instructions](https://docs.arduino.cc/arduino-cli/installation/) and [Arduino core](https://github.com/arduino/ArduinoCore-mbed) checked 5 October 2026.

## Candidate integration and unresolved protection

VERIFIED OEM: Opta Lite12–24 V supply, at12 V maximum2 W; IP20. The drawing shows70 x88.8 mm front dimensions and56.8 mm depth plus4.3 mm projection. It does not fit the current40 mm deep reservation in a normal DIN orientation. RECOMMENDATION: a separate low-voltage bench/control enclosure, not a new tower CAD branch. Hammond1554XA2GY300 x200 x120 mm is a verified enclosure candidate only; mounting plate, DIN rail, buttons, cable entries, clearances and cooling are not released. A drilled enclosure does not inherit the stock ingress rating.

The controller adds0.167 A at its maximum published12 V consumption. Fans plus controller alone demand1.567 A /18.8 W, leaving0.433 A before hub, speed-controller, input and other loads/startup. This is arithmetic, not sufficient supply proof.

The firmware cannot detect an internal fan reset with power still present, hub recovery while RUN remains true, welded contacts, a frozen MCU, safe standstill or actual guard access. Opta is ordinary control, not a safety PLC. Existing project restart/protection requirements stay OPEN and unchanged. An appropriately reviewed independent protective system must act independently of this firmware where required. Do not bridge PR1 to make this candidate run.

Primary sources checked5 October2026:

- [Arduino collective datasheet](https://docs.arduino.cc/resources/datasheets/AFX00001-AFX00002-AFX00003-datasheet.pdf), revision shown1 October2026; electrical/physical data, not complete-device approval.
- [Arduino pinout, Lite on page3](https://docs.arduino.cc/resources/pinouts/AFX00001-AFX00002-AFX00003-full-pinout.pdf). The OEM sheet is CC BY-SA4.0; linked, not republished or traced. This project's drawing is original; identifiers and technical facts are used as references.
- [Arduino official Opta mapping example](https://docs.arduino.cc/tutorials/opta/getting-started-with-interrupts). This sketch polls; it does not use that example's code.
- [Hammond exact enclosure](https://www.hammfg.com/part/1554XA2GY). Shipping weight is not installed net weight. No price or India stock claimed.

Next release evidence: accepted hazard allocation and independent protection, exact physical harness and source fault/time behavior, assessed enclosure/controls/retention, board compilation and unpowered inspection, followed by qualified dummy-load commissioning. No fan or energized live fault testing is authorized by these files.

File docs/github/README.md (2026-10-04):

# Prototype CI template

`prototype-checks.yml` is a prepared workflow template, not an active GitHub Action. It checks local README targets and current standard-library D01 analysis tools on Linux.

The authenticated GitHub credentials used for this update have repository permission but lack the `workflow` scope, so GitHub rejected creating the file under `.github/workflows/`. The template is retained here without expanding account permissions.

To activate it, a maintainer with workflow write permission can copy it to `.github/workflows/prototype-checks.yml` and commit through the normal review process. No additional Python dependencies are needed. Tests remain arithmetic and abstract software checks; they do not certify the physical unit.

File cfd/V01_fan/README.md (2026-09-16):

# V01 — Actual KVO 250 / empty Concept A tower

Status: RUN COMPLETED; PARTIAL / NON-CONVERGED, final fields at iteration 4000.

This case uses the supplied six-point Systemair KVO 250 curve, not the former fixed-300-Pa placeholder. The placeholder was never run and is preserved in archive_placeholder/.

The model predicts about 1476 m³/h, 17.33 Pa fan-static-equivalent head, and 32.46 Pa tower static-pressure difference. These are distinct pressure measures. Residual criteria are not fully met.

- Full setup: ../../docs/CFD_V01_FAN.md
- Results and limitations: ../../results/CFD_V01_FAN_RESULTS.md
- Figures and raw metrics: ../../results/CFD_V01_FAN/
- Exact input provenance: fan_implementation.json
- Mesh: copied byte-for-byte from V00; no CAD edits or new cells.
- Logs: logs/foamRun_kvo.log (initial solve, post-End cleanup crash) and logs/foamRun_kvo_continue.log (clean diagnostic continuation).
- Existing-run guards prevent automatic resets. See setup documentation before reproducing.
- The active controlDict describes continuation to iteration 4000 and preloads the locally compiled boundary library. Initial dictionaries are in logs/initial_kvo_setup/.

No filters, particles, water, solar, batteries, optimization or dashboard are included. No final fan or purification claim is made.

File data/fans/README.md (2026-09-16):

# Fan Data Requirements

## Purpose

This document defines the minimum data required from a real fan datasheet before that fan can be used in any engineering calculation or CFD model for the AQI Tower project. Nothing in this file is a product selection or a purchase recommendation.

## Why this exists

Phase 5 CFD (V00) established that the empty tower geometry produces approximately 33 Pa of flow-induced pressure loss at a placeholder inlet velocity of 1 m/s (Q = 1,512 m³/h). That number is an indicative data point, NOT the fan requirement. The actual system resistance at any real operating point depends on flow rate (Q²-scaled), the yet-unknown filter pressure drops (HEPA, prefilter, possible biochar stage), and minor losses from geometry that V00 did not model with full accuracy. A fan must be selected against a complete, documented system resistance curve — not against a single CFD number from an empty-tower placeholder run.

## Minimum required datasheet fields

Every candidate fan must provide the following before it is included in any comparison or calculation. If a field is absent, mark it MISSING and do not estimate it.

| Field | Symbol | Unit | Notes |
|---|---|---|---|
| Fan curve: at least 5 (Q, ΔP) points | — | m³/h, Pa | Static pressure rise vs. volumetric flow. Must cover shutoff (Q=0) and free-delivery (ΔP=0). |
| Maximum static pressure (shutoff head) | ΔP_max | Pa | At Q = 0. Must be sourced from the curve or datasheet, not estimated. |
| Maximum free-delivery flow | Q_max | m³/h | At ΔP = 0. |
| Rated operating point | Q_rated, ΔP_rated | m³/h, Pa | Manufacturer's stated duty point. |
| Fan type | — | — | Axial / centrifugal / mixed-flow / cross-flow. |
| Drive type | — | — | AC induction / EC (electronically commutated) / DC brushless / belt-driven. |
| Electrical supply | V_supply | V, Hz | Nominal voltage and frequency (e.g., 230 V / 50 Hz). |
| Input power at rated point | P_in | W | Electrical input. Required to estimate operating cost and power budget. |
| Efficiency at rated point | η | % | Total or static efficiency; note which. |
| Speed at rated point | n | RPM | For scaling and acoustic reference. |
| Frame / housing size | — | mm | Outer envelope: width × depth × height (or diameter). Must fit the tower cross-section. |
| Inlet / outlet duct diameter or dimensions | — | mm | For connection design. |
| Weight | — | kg | Structural load on tower. |
| Noise level | L_w or L_p | dB(A) | At rated point; note reference distance if L_p. |
| IP rating | — | — | Required for water-separation stage proximity. |
| Operating temperature range | T_min, T_max | °C | |
| Manufacturer part number and revision | — | — | Needed to verify the exact datasheet used. |
| Datasheet URL or document reference | — | — | Must be a real, retrievable source. |

## Minimum required for CFD fan BC (V01_fan)

To implement the OpenFOAM `fan` pressure-jump boundary condition the following are additionally required:

- The complete fan curve as a table of (Q, ΔP_static) pairs in SI units (m³/s, Pa), at the specific operating speed.
- If the fan speed is variable (EC motor): the curve at the speed closest to the estimated operating speed, or curves at two speeds for interpolation.
- The face area of the fan inlet or the duct cross-section where the BC will be applied (to convert patch-integrated volume flow to face velocity).

If real fan curve data are not available, the V01_fan case MUST be run with an explicit PLACEHOLDER pressure jump and documented as such. Fan curve data may NOT be invented or estimated from first principles without a physical measurement or manufacturer-provided curve.

## Current status (updated Phase 6D, 2026-09-05)

| Candidate | Data file | Evidence | Fan curve | Max ΔP (Pa) | Status |
|---|---|---|---|---|---|
| EBM-Papst G2E140-AE77-01 | `ebmpapst_G2E140_AE77-01.json` | **B** (upgraded) | NOT in operating instructions — performance datasheet needed | UNKNOWN (thermal-limit claim was misinterpretation) | **Tier 3 — re-evaluation needed** |
| EBM-Papst G2E140-AI28-A5 | `ebmpapst_G2E140_AI28-A5.json` | D | Not extracted | UNKNOWN | Tier 3 — low priority |
| EBM-Papst R2E225-RA92-09 | `ebmpapst_R2E225_RA92-09.json` | C | PDF unreadable (binary) | ~425 Pa indicative | Tier 2 — potentially suitable |
| EBM-Papst R2E225-RA92-23 | `ebmpapst_R2E225_RA92-23.json` | C | Available in PDF, not read | ~580 Pa indicative | Tier 2 — potentially suitable |
| Systemair KVO 250 | `systemair_KVO_250.json` | **A** | **6 points: 2 confirmed + 4 graph-digitized (Phase 6D)** | **~688 Pa ±20 Pa (CORRECTED — was 850 Pa)** | **Tier 1 — CFD READY WITH DIGITIZATION UNCERTAINTY** |

The KVO 250 now meets the minimum data requirements (Evidence Level A with 6 fan curve points). See `docs/FAN_DATA_GAPS.md` and `docs/FAN_CURVE_AUDIT.md` for detail.

## What to do next (priority order, Phase 6D)

1. ~~**Digitize KVO 250 fan curve points**~~ — COMPLETED Phase 6D. 6-point curve extracted via PyMuPDF.
2. **[HIGHEST PRIORITY] Confirm baffle face area** from Phase 4 FreeCAD CAD model, then implement V02_fan with real KVO 250 fan BC.
3. **Obtain ebm-papst G2E140-AE77-01 PERFORMANCE DATASHEET** (separate from operating instructions). Determines whether the G2E140 series has adequate shutoff head for this application.
4. **Find text-readable R2E225-RA92-09 fan curve.** Both PDF sources returned binary. Contact ebm-papst India or use an HTML datasheet source.
5. **Obtain multi-point HEPA ΔP curve** — contact Freudenberg or equivalent for ΔP at 3+ face velocities.
6. **Confirm tower filter face area** from Phase 4 FreeCAD CAD model.

Completed actions (Phase 6C + 6D):
- G2E140-AE77-01 operating instructions read — thermal-limit claim corrected (Phase 6C)
- KVO 250 catalog read — Evidence A, 2 confirmed fan curve points obtained (Phase 6C)
- Airflow discrepancy (R2E225-RA92-09) resolved — 705 m³/h at 50 Hz confirmed (Phase 6C)
- First HEPA H13 filter data obtained (Freudenberg, single point) (Phase 6C)
- KVO 250 fan curve expanded to 6 points via PyMuPDF vector extraction — shutoff head corrected to 688 Pa — CFD READY (Phase 6D)

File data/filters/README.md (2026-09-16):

# Filter Data Requirements

## Purpose

This directory holds structured data records for filtration components being evaluated for the AQI Tower. Filter data drives the system resistance curve — without at least one confirmed filter ΔP relationship, the operating point of any fan cannot be calculated.

## Why this exists

The AQI Tower system resistance is dominated by filter pressure drop, not by duct losses. The V00 CFD empty-tower result (~33 Pa at 1512 m³/h) is a minor term. Even a single clean H13 HEPA filter adds 80–300+ Pa depending on face velocity. Without real filter data, fan selection is speculation.

## Minimum required data fields

Every filter record must include the following before it can be used in any calculation. Mark missing fields MISSING — do not estimate them.

| Field | Symbol | Unit | Notes |
|---|---|---|---|
| Filter class / grade | — | — | EN 1822: E10–U17; ISO 29463; MERV; or equivalent |
| Dimensions (face) | W × H | mm | The flow-facing area |
| Depth | D | mm | Media pack depth |
| Rated face velocity | v_rated | m/s | Manufacturer's stated test velocity |
| Rated airflow | Q_rated | m³/h | Must be consistent with face area × face velocity |
| Initial pressure drop at rated conditions | ΔP_initial | Pa | Clean filter, sourced from manufacturer |
| Pressure drop vs. face velocity — table or curve | ΔP(v) | Pa vs m/s | At least 3 points preferred; single point acceptable if noted |
| Terminal pressure drop (replacement criterion) | ΔP_terminal | Pa | At end of service life; if stated |
| Frame material | — | — | Galvanized steel / aluminium / plastic |
| Media type | — | — | Glass fibre / synthetic; MiniPleat / deep-pleat / flat |
| Manufacturer and part number | — | — | Exact article number or model |
| Source URL or document reference | — | — | Must be a real, retrievable manufacturer source |

## Evidence levels (same as for fans)

| Level | Meaning |
|---|---|
| A | Official manufacturer datasheet with ΔP curve (multiple v points) directly obtained |
| B | Official manufacturer product page with nominal ΔP and rated conditions; single point only |
| C | Distributor or secondary source with partial data |
| D | Literature estimate only; no product-specific data |

## How filter ΔP enters the system curve

For turbulent-regime filter media (typical HEPA, prefilter):

- ΔP scales approximately **linearly** with face velocity: ΔP ∝ v. This is the viscous-dominated Darcy regime.
- Face velocity at the AQI Tower operating point: v = Q_operating / A_filter (m/s), where A_filter is the net filter face area (m²).
- Single-point linear scaling from a rated condition: ΔP_filter(Q) ≈ ΔP_rated × (Q / Q_rated), where Q_rated = v_rated × A_filter × 3600 m³/h.
- This scaling is valid only for a **clean** filter. Loaded filters may show different behaviour. If possible, use a multi-point curve.

**IMPORTANT:** This linear scaling from a single rated point is an approximation. Always note the assumed scaling when using it. It must not be cited as a measured ΔP for the AQI Tower — it is an extrapolation.

## Current status (Phase 6C, 2026-09-05)

| Product | File | Evidence | ΔP data | Status |
|---|---|---|---|---|
| Freudenberg SF13-B-0593x0593x292 (H13, galvanized steel) | `freudenberg_SF13B_593x593x292.json` | B | 300 Pa at 2.84 m/s (nominal, one point) | FIRST REAL DATA POINT — single point only |

No filter has reached Evidence Level A (full ΔP vs. v curve). The single Freudenberg data point is the first real manufacturer filter data in this project.

## Needed next actions

1. **Get full ΔP curve for the Freudenberg SF13-B (or equivalent H13 product).** Contact Freudenberg Filtration Technologies or obtain a technical datasheet with ΔP at 3+ face velocities.
2. **Determine the actual filter face area for the AQI Tower.** The tower cross-section from the FreeCAD model (Phase 4) sets the available filter area. If the filter must be smaller than the cross-section, a transition frame is needed.
3. **Obtain prefilter (G4/F7/M5 class) ΔP data.** A coarse prefilter stage will protect the HEPA from rapid loading. Its ΔP at tower operating conditions is currently entirely unknown.
4. **Obtain any data on biochar packed-bed ΔP** (Ergun equation parameters: particle diameter, void fraction, bed depth).

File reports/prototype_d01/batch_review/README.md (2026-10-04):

# Current handoff consistency and parts

`CURRENT_COMBINED_PARTS_REGISTER.csv` reconciles the current R03M indoor cabinet
and E05 external control-module candidates. It is an onboarding register, not
a purchase or construction approval. Candidate product identity does not imply
India stock, price, delivered dimensions, protective suitability or actual fit.
Do not add historical BOM quantities to this register; custom fastening uses
the controlling mechanical schedule.

`HANDOFF_CONSISTENCY.json` and `AUDIT_FINDINGS.csv` record the last executable
digital audit. Run `python scripts/maintenance/check_d01_handoff_consistency.py`
from the repository for a current read-only result. Existing bundled report
Python enables the optional PDF extraction check without installation.
`--write-results` refreshes only these audit reports; rebuild both bundles
afterward, then run the checker again without that flag.

The checker validates unchanged 493-object native tower provenance, current
E05 three-pair service evidence, default-disabled firmware and target-build
source hashes, current pressure inputs, package manifests and source copies.
Text files may be content-identical with LF/CRLF differences; this is recorded
explicitly while ZIP manifests always require exact payload bytes. Historical
IH02 pages are preserved references, not the current product/controls decision.

Passing this checker proves digital consistency only. Physical prototypes and
physical tests remain zero. Guards/structure/seals, exact connectors, protection,
commissioning and measured performance are not approved by a software audit.

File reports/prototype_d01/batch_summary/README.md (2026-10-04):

# Single-batch engineering result — 5 October 2026

Three parallel agents worked on mechanics, electrical design and handoff consistency. Root integrated their results and corrected the E05 pair-recording indentation bug. Original R03M geometry and historical IH02 evidence remain intact. **Review handoff, NOT construction or energization release. Physical prototypes: 0.**

## Concrete engineering findings

- Actual saved model: two 43 mm filter closing gaps, 36 mm sleeves, 7 mm stack offset. The new robust interval solver determines whether a fixed stop covers supplied filter/gasket/flatness intervals. In the clearly ASSUMED broad tolerance example, no fixed stop works; no seal PASS or machining setting is invented.
- Four actual eight-bolt cabinet groups now have in-plane force/moment demand calculations and equilibrium tests. Material/joint capacity, racking, withdrawal, perforated guards and full stability remain unverified.
- Electrical screen separates total source load from the fan path. Fans plus Opta yield a 1.3095× fan-current multiplier ceiling before auxiliaries, 1.2381× with an ASSUMED 0.10 A auxiliary load. These are data-acquisition thresholds, not measured inrush approval.
- An ASSUMED source-limited 2 A fault does not establish clearing of the screened 2 A fuse. No fuse/holder/PR1 selected. Hazard allocation distinguishes accessible motion and service isolation from performance interruption, preserving existing restart requirements.
- E05 assumed service volumes clear each other without reduction. Audit found the recorded service-pair list omitted a true pair and duplicated a stale self label; corrected generator now requires exactly three distinct non-self pairs. Actual intersection checks were already inside the original loop and passed.
- Current 28-line parts register replaces outdated procurement navigation, not historical evidence. Root-generated current pressure budget and freshly copied input files retain exact byte hashes. Package audit distinguishes line-ending-only equivalence from actual content differences; ZIP manifests are always strict byte checks.

## One command

From project root, using existing Python:

```
python scripts/maintenance/run_d01_release_batch.py
```

From the extracted technical bundle's `engineering/` folder:

```
python scripts/maintenance/run_d01_release_batch.py --calculations-only
```

This runs six calculation/synthetic-test programs; project-root mode also checks the complete handoff. It never installs, flashes, wires or energizes. The `--calculations-only` report is stored in BATCH_VERIFICATION.json; the independent package audit is in batch_review/HANDOFF_CONSISTENCY.json. Outcomes are digital evidence, never safety/physical approval.

Current deliverables: mechanical_package/batch_closure; electrical_package/batch_closure; batch_review/CURRENT_COMBINED_PARTS_REGISTER.csv; control_module/CURRENT_RELEASE_GATES.csv. The consolidated PDF begins with current build decisions and E05/E02 diagrams; the earlier evidence follows unchanged.

## Real blockers retained

Exact filter/frame/gasket and harness geometry; material/guard/joint/stability acceptance; actual protective function/circuit and fault coordination; real component retention, terminations/entries and thermal evaluation; agreed room/targets/instruments; authorized procurement, fabrication and qualified commissioning, followed by physical performance measurements. Numeric low-current contact suitability remains unverified because the current OEM wording is ambiguous. No prices, stock or completion dates invented.

Generated cache/backup duplicates are excluded from the delivery copy; original/local evidence and backups remain untouched. No new supplier contacts, purchases, software installations or physical results in this batch.

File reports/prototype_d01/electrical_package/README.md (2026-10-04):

# D01 electrical review E00 - 4 October 2026

**E03 body packaging:** [dimensioned external control module and editable CAD](control_module/README.md). Checked against private exact Hammond STEP, not a drilling release or completed rated panel. Closed-lid NA-FC1 access unresolved; do not run an open box. Tower CAD unchanged.

**E02 ordinary-control candidate, 5 October:** [actual-terminal bench drawing](AQI_D01_OPTA_BENCH_REVIEW.pdf), [specific hardware/fuse integration screen](OPTA_INTEGRATION_SCREEN.json), [host test results](OPTA_HOST_CHECKS.json), [implemented firmware](../../../firmware/d01_opta_review/README.md), [real target-build evidence](OPTA_BOARD_BUILD.json). Opta Lite candidate, real START/STOP/RESET C++ logic, OEM I1–I5/output1 mapping and external enclosure/fuse screen.1,041 host assertions include1,024 one-step cases; default sketch compile/link PASS for official Opta core4.6.0 with CLI1.5.1. No upload, hardware or safety qualification. Relays disabled by default. This does NOT complete protective PR1 or solve internal fan/hub recovery. Existing release gates remain. Included as separate PDF/code in current technical ZIP;50-page main PDF preserved.

**Current supplement, 5 October:** [four-page E01 power/wiring drawing](AQI_D01_POWER_AND_WIRING_SUPPLEMENT.pdf), [catalogue/conditional coordination calculation](POWER_COORDINATION.json) and [rated/reference parts](E01_RATED_PARTS.csv). Connector-level chain, official P14 Max pin functions, supply/controller/hub limits and protection coverage.20 assumed load scenarios and36 copper-drop examples; ten analytic/synthetic tests pass. No completed physical terminal schedule, fuse/wire selection or implemented protective restart. E00 PDF/ZIP preserved; E01 is included in the current50-page shareable technical handoff/ZIP.

Reproduce: `python scripts/analysis/d01_electrical_closure.py`, `python scripts/analysis/test_d01_electrical_closure.py`, `python scripts/reports/build_d01_power_closure.py` (ReportLab and pypdfium2 needed only for drawing/render). Current ARCTIC/Noctua primary source URLs and access date are in JSON. Only fan1 RPM is forwarded upstream; no four-fan protective feedback. Larger adapter alone cannot uprate the selected24W hub input. **Do not bridge unselected PR1 or energize this drawing.**

Later supplementary evidence: [protective-control candidate decision](PROTECTIVE_SELECTION_DECISION.md) and PROTECTIVE_CANDIDATE_SCREEN.json. Three OEM relays screened; none selected as a complete protective assembly. Eight reproducible checks pass. These supplements are not included in the original E00 PDF/ZIP.

Open **AQI_D01_ELECTRICAL_REVIEW.pdf**. This is the consolidated package 2 review for R03M, NOT released wiring or energization instructions.

Includes: OEM power-reference schematic; nominal and startup-sensitivity arithmetic; interface CSV; reference/unresolved BOM; enclosure/cable integration constraints; restart requirements with executable abstract tests; physical commissioning cases and three explicit electrical release blockers.

The protective module remains UNSELECTED. Hardware implementation, conductor/fuse ratings, terminal assignments, protective reliability and physical commissioning are not complete. Model PASS does not change this status. All physical tests NOT EXECUTED; prototypes 0.

The hub self-resetting protection and single upstream RPM channel prevent claiming this OEM chain is an independent four-fan protective system. Keep SATA unused and logger independent. No purchases, installations, supplier messages or publication performed.

Reproduce from repository root using Python with ReportLab:
`python scripts/analysis/d01_control_acceptance.py`
`python scripts/reports/build_d01_electrical_package.py`

Next meaningful work: finish rated protection/interface engineering and the actual filter/flow validation package, not another cosmetic CAD branch. Outdoor/public deployment remains unqualified.

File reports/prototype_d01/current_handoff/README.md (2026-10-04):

# START HERE — one current D01 review handoff

**Continued by [package1 R03M mechanical](../mechanical_package/README.md).** That assembly supersedes R02G mechanical details below; this R02G handoff is preserved as historical evidence. Use R03M panel/base/guard files and fastener lengths together. No fabrication release in either revision.

03 October 2026. **Design review only. NOT construction-ready. Physical prototypes:0.**

Open [AQI_D01_CURRENT_REVIEW_PACKAGE.pdf](AQI_D01_CURRENT_REVIEW_PACKAGE.pdf). It combines a plain-language project handoff with current pressure/electrical boundaries, three remaining build gates and10 panel drawings taken directly from the current CAD. It replaces the need to assemble an understanding from earlier revision PDFs. Historical evidence remains preserved.

[Download the current review bundle](AQI_D01_CURRENT_REVIEW_HANDOFF.zip). It preserves project-relative paths and includes current CAD, PDF, panel DXFs, inventory, checks and the three current-generation scripts. MANIFEST.json records hashes. It is not the full project history or a released fabrication pack. Required CAD/runtime dependencies are not bundled.

## Current authority

- [R02G integrated FreeCAD assembly](../r02_guards/D01_R02G_ASSEMBLY.FCStd), [STEP](../r02_guards/D01_R02G_ASSEMBLY.step): geometry authority; no assembly change in this handoff.
- [Ten panel DXFs](panel_DXF_REVIEW_ONLY/): current CAD-face extraction, mm, no kerf compensation or released tolerances/materials. Do NOT send directly for cutting. Other brackets/guards/hardware are not covered by these flat-panel files.
- [Complete CAD object inventory](CAD_PART_INVENTORY.csv):245 rows, including reservations, simplified envelopes and inherited notes. This is NOT a complete purchase list.
- [OEM references and missing items](COMPONENT_AND_MISSING_ITEMS.csv): covers unmodeled controls, missing hardware, seals and services. Combined with the inventory, this exposes omissions rather than silently treating them as finished parts.
- [Current pressure CSV](CURRENT_PRESSURE_BUDGET.csv), [calculation evidence](CURRENT_PRESSURE_BUDGET.json).
- [Whole-assembly audit](assembly_audit.json), [panel geometry](current_panels.json), [three build gates](BUILD_GATES.csv).

## What changed in this pass

DETECTED: earlier deliveries were fragmented and delta-only audits did not constitute a single whole-assembly handoff. This pass checks the complete current assembly, extracts all10 flat panels from actual BRep faces, verifies face-area times thickness against part volume, and inventories every object.29,116 modeled part pairs pass the0.05 mm3 clash threshold;774 pairs involving reservations or guard-to-guard seams are excluded. Native/STEP checks were already completed for R02G; no new physical result is claimed. The source CAD hash is recorded and unchanged.

New current-geometry pressure budget includes the350x270 mm openings and a separate reducer-path sensitivity. At300 total m3/h, each filter sees150 m3/h and the K=1 scenario leaves14.61 Pa filter allowance after assumed losses. This is a balance allowance, NOT an operating target approved by the user, actual filter resistance, performance margin or measured airflow. At400 total, the same assumptions leave negative allowance even before adding a filter. Eight arithmetic checks pass. No filter curve was invented and no old R01 flow prediction is presented as R02G performance.

## When does the preparation end?

There are three closure packages, not a commitment to one chat turn per small feature:

1. **Mechanical (assistant prepares; still OPEN):** finish guard face/corner/rivet joins, remaining cabinet/fan/M5 fastening stacks, sealing/compression details, cable housing/entry, and load/access/stability checks. Some quantities, materials and strengths are still unknown. Selected-component dimensions and qualified physical fit/review are needed before release.
2. **Electrical (assistant prepares; still OPEN):** rated protective isolation/restart arrangement, exact connectors/cables/enclosure and installation checks. The present OEM speed-control chain does NOT implement the stated protective functions. Qualified review and commissioning remain necessary, not delegated to an unconfirmed friend.
3. **Performance evidence (still OPEN):** actual filter resistance and seal behavior, then installed flow/power/noise and controlled indoor particle trials. Where manufacturers do not publish the needed data, measurements of real parts cannot be replaced with internet research. No supplier-contact task is being assigned to the user.

Gates1/2 and actual component fit govern safe construction/energization; gate3 governs what performance can be claimed. A safe test assembly may be built to discover performance only after its mechanical/electrical release, not by declaring unknown performance a safety approval. Internet/public evidence work may continue, but repeated cosmetic CAD revisions are not progress on the missing test evidence.

No exact number of days is defensible: no approved parts order, confirmed stock/delivery, fabricator/reviewer booking or test location exists. Do not confuse assistant computation time with supply, fabrication and test time. Funding should be staged for samples, confirmed parts, fabrication, review/commissioning and measurement. No prices or total cost fabricated.

## Sources / assumptions / unknowns

- FACT: indoor first test, funding but no college lab, eventual outdoor goal, no physical prototype.
- DETECTED: saved R02G geometry, public OEM references and archived curve numeric data.
- RECOMMENDATION: finish one supervised indoor particulate demonstrator; keep outdoor/weather/solar/gas/water and network work outside this first build release.
- ASSUMPTION: equal parallel fan/filter flows, full2800 rpm, density1.2 kg/m3, guard active area300x300 mm at40% open, plenum K1.5, guard K1.5 each, fan-aperture-based installation allowance K1, reducer K0.5/1/2. Added reducer loss may overlap the existing plenum allowance; none of these K values is validated. No bypass assumed. No physical uncertainty band implied.
- UNKNOWN: selected filter clean/loaded curve and frame landing, installed fan performance, seal compression/leakage, materials/strength, mass/tipping, protective electrical implementation, procurement and test outcomes.

Source references (previously accessed03 October2026): [ARCTIC numeric workbook](https://support.arctic.de/products/p14-max/techdocs/P14%20Max%20-%20PQ%20Curve%20for%20CFD.XLSX), [ARCTIC support](https://support.arctic.de/p14-max), [IKEA STARKVIND104.633.30](https://www.ikea.com/in/en/p/starkvind-filter-for-particle-removal-10463330/), [Noctua NV-PS1](https://www.noctua.at/en/products/nv-ps1), [NA-FH1](https://www.noctua.at/en/products/na-fh1/specifications), [NA-FC1 total-current FAQ](https://www.noctua.at/en/support/faqs/how-many-fans-can-i-connect-to-the-na-fc1-controller).

The IKEA part is intended by its OEM only for STARKVIND. This custom integration is experimental, not endorsed. No HEPA/MERV rating is assigned to our current assembly. ARCTIC numeric/brochure discrepancies remain unresolved; the numeric curve is not averaged with the brochure. Hardware dimensional sources are in the preserved R02H/R02G READMEs. OEM material is evidence, not an open-source manufacturing licence. The handoff ZIP does not redistribute OEM downloads.

The aqi-build-review skill drove whole-assembly verification, same-flow pressure accounting, and the explicit separation of digital work from physical release. No purchase, install, contact or public publishing occurred.

## Reproduce

```powershell
& 'D:\Applications\FreeCAD 1.1.3\bin\python.exe' scripts/geometry/audit_d01_current.py
& 'C:\Users\G15 5530\.cache\codex-runtimes\codex-primary-runtime\dependencies\python\python.exe' scripts/analysis/d01_current_pressure_budget.py
& 'C:\Users\G15 5530\.cache\codex-runtimes\codex-primary-runtime\dependencies\python\python.exe' scripts/reports/build_d01_current_handoff.py
```

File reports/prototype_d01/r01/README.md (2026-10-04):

# D01 R01 construction details

R01 continues the same D01 assembly. **Design review only; not released for fabrication, procurement or energizing.** R00 is preserved as historical evidence. Physical prototypes built: 0.

Start with `D01_R01_CONSTRUCTION_DETAILS.pdf` (five visually inspected drawing sheets). The updated native CAD is `D01_R01_ASSEMBLY.FCStd`; the neutral export is `D01_R01_ASSEMBLY.step`. The illustration comes from this CAD, not an AI concept image.

`BOM_R01.csv` consolidates the original product references and new hardware; `FASTENERS_R01.csv` gives locations and proposed sizes. The R01 ZIP includes these files and the R00 base needed to reproduce the revision. Do not treat the R00 report included for context as the latest cutting or pressure basis.

## Completed in R01

- Eight guard mounting angles with rivet holes, four shared guard bolts, washer/nut envelopes and corresponding holes through the fan plate. Actual rivets remain unselected/unmodeled.
- Thirty-two proposed M4 cabinet through-joints with matching holes in panels and cleats; eight top/base timber-fixing locations.
- Eight filter-shelf support angles with corresponding seat/ledge holes and proposed screw shafts. Flush head/countersink details await actual screws.
- Eleven revised panel-outline/drilling DXFs, replacing the R00 cutting geometry for review. Four separate shelf drawings avoid assuming front/rear/left/right hole patterns are identical.
- An external cable-routing reservation. **It is not a drilled gland hole or wiring release.**
- Revised guard resistance calculation: 10 mm solid border leaves a 300 x300 mm perforated field. At assumed40% field porosity, free area is0.036 m2 per face, versus0.04096 m2 in R00. Calculated low/middle/loaded flows are359.2 /337.1 /297.5 m3/h. These are unmeasured scenarios, not a guaranteed range or CADR.
- Conditional bracket-load arithmetic, explicitly without a material allowable or structural PASS. Do not treat its illustrative50N/2kg cases as a safety standard or validated design load.

The `aqi-build-review` procedure required the changed guard geometry to feed back into pressure screening, rather than silently retaining the higher R00 estimates.

## Checks and exclusions

`checks.json` records163 valid modeled objects,12,675 nominal pair checks with no positive-volume clashes, native reopen and STEP volume checks. R00's native assembly SHA256 is recorded and remains unchanged. `pressure_results.json` contains nine arithmetic checks; `load_screening.json` adds five checks. Nominal clearance does not establish tolerance or strength.

Excluded: cable/control reservation envelopes, inherited guard-to-guard seams, actual perforation geometry, screw threads, several heads/washers/nuts, extrusion bend fillets and rivet heads. Perforations in the rendered image are a visual annotation of the proposed pattern. Wood screw cores/pilots are layout envelopes, not verified thread engagement.

The full R00 product evidence and limitations remain in `../README.md`. No new OEM suitability, stock, price or licence claims were established this turn. No external party contacted, no software installed and no purchase made.

## Construction boundary

The new attachment geometry is prepared; these specific items remain open:

1. Exact fan/filter availability and revision, filter resistance curve and real frame/seal landing.
2. Angle and guard material/grade, bend fillets, cage seam method, rivet grip, final fastener products, joint bearing/pull-out, guard reach/deflection, mass/centre of gravity and stability.
3. Timber screw type/pilot and holding capacity, top-seam tape/product, permanent sealant and physical leakage checks. Carry from the base, not the unqualified lid or clamping frames.
4. Selected flush shelf-head geometry, remaining plywood thickness and flat filter seating; do not blindly countersink from a generic hole drawing.
5. Actual cable gland/entry that maintains guard protection, restraint and extension lengths, enclosure mounting, startup current and electrical commissioning.
6. Rated restart prevention remains missing. R01 does not implement or waive the existing manual-restart/interlock requirement. No unattended use or energization release.

Shared guard bolts require supporting both guards while dismantling, with power unplugged and rotation stopped. Actual joint/safety review may require separate retained guard attachments; no independent-access safety function is claimed.

## Reproduce

Run from project root using existing runtimes:

```powershell
& 'D:\Applications\FreeCAD 1.1.3\bin\python.exe' scripts/geometry/detail_d01_r01.py
& 'C:\Users\G15 5530\.cache\codex-runtimes\codex-primary-runtime\dependencies\python\python.exe' scripts/analysis/d01_r01_checks.py
& 'C:\Users\G15 5530\.cache\codex-runtimes\codex-primary-runtime\dependencies\python\python.exe' scripts/reports/build_d01_r01.py
```

R01 imports the saved R00 native assembly. Do not overwrite that base with another design. R01 currently uses explicit construction coordinates; it is reproducible geometry, not a fully constrained parametric production model.

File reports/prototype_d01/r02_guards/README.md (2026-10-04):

# D01 R02G — independently attached fan guards

03 October 2026. **REVIEW ONLY: not released for manufacture or energizing.** Same integrated D01 assembly, continuing R02H. Physical prototypes: **0**.

## Deliverables

- [Two-sheet guard mounting drawing](D01_R02G_GUARD_MOUNTINGS.pdf)
- [Integrated FreeCAD assembly](D01_R02G_ASSEMBLY.FCStd) / [STEP](D01_R02G_ASSEMBLY.step)
- [Guard hardware delta BOM](GUARD_DELTA_BOM.csv)
- [Checks and source hash](checks.json) / [mount coordinates](mounts.json)

## Change and reason

DETECTED: R01 through R02H used four shared bolts to attach both upper and lower guard brackets. This coupled their retention. RECOMMENDATION implemented in CAD: four bolts per guard, with separate locations. Removing one set no longer removes the other's modeled attachment. This does not establish that either guard is safe or sufficiently strong.

Outer brackets now begin at y100 and220 mm, with bolt centres y120 and240. Inner brackets retain starts40 and280, bolt centres60 and300. Both sets use x105 and445. The9 mm fan plate gets four additional4.5 mm holes. Outer side skirts get a NEW blank hole pattern at y110/130/230/250,z590; omit historical y50/70/290/310 holes. The CAD fills the historical holes to describe this new blank, NOT a physical hole-plugging instruction. Bracket names retain old identifiers; use current coordinates, not the numeric name suffix.

Proposed hardware: eight M4x20 cap screws, eight7 mm AF x5 mm nuts and sixteen12 mm OD x1 mm washers. Washer bore4.3 mm remains assumed. These replace four shared M4x25 screws, four nut envelopes and eight earlier washers; do not add both hardware sets. Nominal screw projection beyond the nut is2 mm; actual locking engagement/tolerances unverified. Material, torque and reuse limits are not released.

## Verification

245 valid objects;8,641 changed-part pair checks have no positive-volume collision above0.05 mm3. Native reopen and STEP validity/volume checks pass. R02H source hash remains unchanged. Unchanged component pairs, reservation objects and inherited guard-to-guard seams are excluded.

Sixteen tool envelope checks clear: at each of eight mounts, an assumed4 mm diameter straight driver shaft extends100 mm above the screw; an assumed12 mm OD socket extends25 mm below the lower washer with clearance for the nut. Own fastening hardware is excluded. These are space reservations, not selected tools. No handles, hands, insertion trajectory, screw extraction motion, tolerance stack or physical access test is claimed. Guard-removal motion itself has not been verified. No new airflow, leakage, strength or physical result exists.

## Sources and evidence limits

Accessed2026-10-03:

- [Accu M4x20 cap screw](https://www.accu.co.uk/metric-cap-head-screws/250243-SSC-M4-20-A4-R360):20 mm under-head length,7 mm head diameter,4 mm head height,3 mm hex drive. Used only for dimensional reference; its coating/material and availability are not selected or verified for procurement.
- [Accu M4 nut](https://www.accu.co.uk/hexagon-nylon-locking-nuts/7958-HNN-M4-A4):7 mm across flats,5 mm height,0.7 mm pitch. Simplified envelope; no modeled threads/nylon insert.
- [Easyfix large M4 washer](https://www.screwfix.com/p/easyfix-steel-large-flat-washers-m4-x-1mm-100-pack/194ft):12 mm OD and1 mm thickness; bore remains assumed.
- [HSE machinery safety guidance](https://www.hse.gov.uk/work-equipment-machinery/introduction.htm) and [maintenance guidance](https://www.hse.gov.uk/work-equipment-machinery/maintenance.htm): supporting safety principles for guarding and isolation. UK guidance is NOT an Indian conformity determination, product certification or a completed risk assessment.

## Assembly review sequence and remaining gate

Prepare revised plate and outer skirt blanks, retaining other specified panel features. Complete reviewed guard face/skirt seams and bracket rivet joints. Fit inner guard independently, then outer guard. With power disconnected and reconnection prevented, verify each set remains retained when the other is removed. Collect loose hardware; these screws/nuts are not captive. Never perform this check with fans moving. Actual tool/reach and retention checks remain to be done physically by a qualified assembler/reviewer.

Unresolved: exact rivets/grip and their strength, skirt corners/face joins, guard deflection and reach protection, captive hardware or equivalent risk reduction, root radii, plate/joint strength, protected cable entry, remaining cabinet M5 hardware, filter resistance/sealing, rated isolation and restart protection. The earlier guard perforations remain a visual annotation; CAD sheets are envelopes. New bolt penetrations require sealing assessment. No physical release, outdoor/public robustness claim or India heat qualification follows from this revision.

The next useful digital closure is guard sheet/rivet joining and remaining cabinet hardware, alongside protective electrical access/isolation design. Filter pressure and seal evidence still block a defensible performance claim.

## Reproduce

From project root:

```powershell
& 'D:\Applications\FreeCAD 1.1.3\bin\python.exe' scripts/geometry/detail_d01_independent_guards.py
& 'C:\Users\G15 5530\.cache\codex-runtimes\codex-primary-runtime\dependencies\python\python.exe' scripts/reports/build_d01_guard_report.py
```

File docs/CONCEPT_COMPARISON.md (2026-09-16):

# AQI Tower — Concept Comparison

## Assessment Boundary

**PRELIMINARY QUALITATIVE ASSESSMENT**

The scores in this document are engineering judgments used to organize the next modelling steps. They are not measurements, simulation results, predicted performance, or proof that any concept satisfies the requirements.

Scoring scale:

- **1 — Poor:** serious conceptual difficulty for this criterion.
- **2 — Weak:** important disadvantages or complexity.
- **3 — Moderate:** plausible, with meaningful unknowns.
- **4 — Good:** favorable conceptual characteristics, still unvalidated.
- **5 — Promising:** particularly useful or clear for this criterion, still unvalidated.

For **pressure-loss risk**, a higher score means lower anticipated risk or easier management; it does not predict a pressure-drop value. No total score is calculated because the project has not assigned criterion weights.

## Concepts Compared

- **Concept A — Vertical Cross-Flow:** one mainly straight path through flat treatment regions into a separate clean-air riser.
- **Concept B — Central Core:** perimeter intake and radial inward flow through annular or segmented treatment regions into a central clean-air core.
- **Concept C — Dual-Sided Intake / Central Exhaust:** two independent mirrored treatment banks feeding a shared central clean-air chimney.
- **Concept D — Radial / Multi-Plenum:** a common distribution plenum feeding multiple parallel treatment branches that recombine in a clean plenum.

## Qualitative Comparison Matrix

All scores are **ENGINEERING JUDGMENT**.

| Criterion | A: Vertical Cross-Flow | B: Central Core | C: Dual-Sided / Central Exhaust | D: Radial / Multi-Plenum |
| --- | ---: | ---: | ---: | ---: |
| Airflow simplicity | 5 | 3 | 4 | 2 |
| Expected flow-uniformity potential | 3 | 4 | 4 | 5 |
| Pressure-loss risk | 4 | 3 | 3 | 2 |
| Filtration integration | 5 | 3 | 5 | 4 |
| Maintenance | 5 | 2 | 4 | 3 |
| Manufacturability | 5 | 2 | 4 | 2 |
| Scalability | 4 | 4 | 5 | 4 |
| Electrical simplicity | 4 | 4 | 3 | 2 |
| Water-stage integration | 3 | 2 | 4 | 4 |
| Sensor integration | 4 | 3 | 5 | 5 |
| CFD suitability | 5 | 4 | 4 | 3 |
| Stakeholder explainability | 5 | 4 | 4 | 2 |

## Score Rationale

### Concept A — Vertical Cross-Flow

- **ENGINEERING JUDGMENT:** The single dominant path, flat treatment slabs, and rectangular plenums make it easiest to explain, parameterize, mesh, manufacture, and service.
- **UNKNOWN:** A compact inlet and downstream extraction region may still create poor face-velocity uniformity.
- **UNKNOWN:** The outlet turn and clean riser may add loss or recirculation.
- **UNKNOWN:** Integrating a wet stage without compromising dry media may reduce its simplicity.

### Concept B — Central Core

- **ENGINEERING JUDGMENT:** Radial inflow offers an interesting path toward broad perimeter intake and compact central extraction.
- **UNKNOWN:** Surrounding walls or obstructions may cause sector-to-sector imbalance.
- **ENGINEERING JUDGMENT:** Annular or segmented seals, drains, media supports, and core access are harder to manufacture and maintain than flat cassettes.
- **UNKNOWN:** Curved or faceted filter availability and replacement method require sourcing evidence.

### Concept C — Dual-Sided Intake / Central Exhaust

- **ENGINEERING JUDGMENT:** Mirrored flat banks combine good filtration access and scalability with a clear shared exhaust path.
- **UNKNOWN:** Unequal surroundings, loading, or sealing may produce left-right imbalance.
- **ENGINEERING JUDGMENT:** Two independent banks make instrumentation and controlled module comparisons easier, but duplicate doors, seals, and possible drains.
- **UNKNOWN:** The merge into a central chimney may cause jets, loss, or short-circuiting.

### Concept D — Radial / Multi-Plenum

- **ENGINEERING JUDGMENT:** Branch-level control and sensing make this concept attractive for modular experiments and treatment isolation.
- **UNKNOWN:** Passive flow division may be poor whenever branch resistances differ.
- **ENGINEERING JUDGMENT:** Multiple junctions, seals, controls, fans, and access paths create the highest integration burden.
- **UNKNOWN:** Balancing devices could improve distribution but also add pressure loss and maintenance.

## Criterion-by-Criterion Interpretation

| Criterion | Current interpretation | Evidence eventually required |
| --- | --- | --- |
| Airflow simplicity | A has the fewest junctions; D has the most branched topology | Flow schematic review, CFD, and physical airflow measurement |
| Flow-uniformity potential | B, C, and D offer distributed flow faces but depend on plenum and resistance balance | Face-velocity maps from CFD and experiments |
| Pressure-loss risk | A appears to require fewer bends and junctions; D has the most potential local losses | Component pressure data, system model, CFD, and pressure measurements |
| Filtration integration | Flat cassette concepts A and C appear easiest to reconfigure | Filter sourcing, seal design, stage pressure data, and service trials |
| Maintenance | A offers the clearest single-face access; B may hide inner/core parts | Mock service review and later maintenance trials |
| Manufacturability | A and C use more repeated flat parts; B and D need more complex fit-up | India-specific sourcing and fabrication review |
| Scalability | C can expand parallel banks; B can add sectors; D can add branches; A can change face area | Size, flow, transport, and cost requirements |
| Electrical simplicity | A or B can use one central fan region; D may require distributed control | Fan architecture, load budget, and fault review |
| Water-stage integration | C or D can isolate a wet bank/branch; B makes drainage most difficult | Wet-subsystem concept test and contamination review |
| Sensor integration | C and D expose bank/branch differences clearly, but need more channels | Measurement plan, sensor placement study, and calibration plan |
| CFD suitability | A is the simplest first domain; B provides the strongest topological contrast | Geometry quality and mesh-independence planning |
| Stakeholder explainability | A has the most direct airflow story; D needs the most explanation | Student/stakeholder design review |

## Candidate Selection

These selections assign modelling roles. They do not choose a final product.

### Best Baseline Concept

**Concept A — Vertical Cross-Flow**

- **ENGINEERING JUDGMENT:** It has the simplest airflow topology, flat stage regions, straightforward service access, and the clearest path to a low-detail parametric model.
- **ENGINEERING JUDGMENT:** It provides a useful reference against which later complexity can be justified.
- **UNKNOWN:** Its actual flow uniformity, pressure loss, bypass behavior, and recirculation remain unproven.

### Best Alternative

**Concept B — Central Core**

- **ENGINEERING JUDGMENT:** It is topologically different from the linear baseline because it uses perimeter intake and radial inward collection.
- **ENGINEERING JUDGMENT:** Comparing it with Concept A can reveal whether broad radial collection offers enough benefit to justify more difficult manufacture and maintenance.
- **UNKNOWN:** Sector balance, central-core loss, sealing, access, and external recirculation require simulation and testing.

### High-Risk / High-Interest Concept

**Concept D — Radial / Multi-Plenum**

- **ENGINEERING JUDGMENT:** Parallel branches could support modular treatment experiments, branch-level sensing, and isolation of an experimental wet subsystem.
- **ENGINEERING JUDGMENT:** It also has the greatest risk of flow imbalance, junction loss, controls complexity, leakage, difficult cleaning, and fabrication burden.
- **UNKNOWN:** Whether these risks can be managed without losing the modular benefit.

### Retained Comparison Concept

**Concept C — Dual-Sided Intake / Central Exhaust** remains a credible concept for later comparison. Its mirrored modular banks may be practical, but it is closer to Concept A than the radial core is, so it is not assigned the “best alternative” role for the first topology comparison.

## Major Engineering Risks Across All Concepts

1. **UNKNOWN:** The intended application and air volume are not defined, so no architecture can be sized or judged against useful airflow.
2. **UNKNOWN:** The primary pollutant and target removal performance are not defined.
3. **UNKNOWN:** Filter resistance, loading behavior, sealing, and bypass may dominate the fan operating point.
4. **UNKNOWN:** Proposed fan counts and locations may interact or operate away from a stable, efficient point.
5. **UNKNOWN:** Plenums and transitions may create uneven treatment-face velocity, recirculation, and dead zones.
6. **EXPERIMENTAL:** The water stage may add moisture carryover, biological or scaling risk, drainage burden, energy use, and maintenance without sufficient pollutant benefit.
7. **SOURCE REQUIRED:** Biochar or biomass-derived media may not treat the selected pollutant or may have inadequate capacity, pressure behavior, or durability.
8. **UNKNOWN:** Inlet/exhaust placement may cause external short-circuiting, particularly when installed near walls or outdoors.
9. **UNKNOWN:** Access, sealing, replacement, cleaning, and safe wet/electrical separation may make a concept impractical.
10. **UNKNOWN:** Size, weight, noise, weather, budget, local sourcing, power, solar contribution, and validation constraints remain open.

## CFD Questions Shared by the Candidates

1. What airflow distribution occurs through each treatment-region face?
2. Where do internal recirculation, separation, high-velocity jets, and dead zones form?
3. How much pressure loss is associated with each plenum, transition, turn, branch, and placeholder treatment region?
4. How do extraction, intake, central, distributed, and push-pull fan-zone placements alter the system flow?
5. How sensitive is flow to unequal stage resistance representing loading, manufacturing variation, or blockage?
6. Does air bypass treatment regions through gaps or unintended paths?
7. How effectively do plenums, diffusers, straighteners, baffles, and turning vanes distribute flow, and what loss do they add?
8. Do the inlet and outlet positions encourage external recirculation or short-circuiting?
9. For Concepts B–D, how evenly does flow divide among sectors, banks, or branches?
10. Which geometric parameters most strongly affect flow uniformity and pressure loss?

CFD cannot establish filter efficiency, adsorption effectiveness, water hygiene, maintenance feasibility, or real fan performance without appropriate source data and physical validation.

## Decision Gates Before a Final Architecture

- **FACT:** No concept can become a final design during Phase 3.
- **UNKNOWN:** Application, pollutant target, airflow/CADR, duty cycle, and constraint targets must be approved.
- **SOURCE REQUIRED:** Candidate fan curves and stage pressure-drop data must be obtained before a meaningful operating point can be assessed.
- **SIMULATION:** Baseline and alternative airflow domains must be compared using the same documented boundary assumptions.
- **EXPERIMENTAL:** Critical component behavior and integrated performance must be measured before performance claims.
- **ENGINEERING JUDGMENT:** A concept should advance only if its predicted airflow advantage is compatible with manufacture, safe service, and physical validation.

## First Modelling Recommendation

**ENGINEERING JUDGMENT:** Build a simple parametric airflow-region model of Concept A first, then a simplified Concept B comparison model. Use the same unknown stage-resistance placeholders and boundary-condition framework so the comparison tests topology rather than arbitrary inputs. Do not add detailed filters, fan blades, particles, water, or final dimensions at the first CAD stage.

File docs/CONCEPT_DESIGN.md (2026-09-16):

# AQI Tower — Concept Design

## Phase 3 Scope

This document explores substantially different physical and airflow architectures before detailed CAD or CFD begins. It does not select final dimensions, fans, filters, materials, treatment order, or performance values.

### Engineering Traceability Labels

- **FACT** — known from the approved project requirements or a recorded source.
- **ENGINEERING JUDGMENT** — a reasoned conceptual recommendation that has not been validated.
- **UNKNOWN** — requires a requirement decision, source, simulation, or physical test.
- **ASSUMPTION** — a temporary modelling input that must be recorded and validated before use.

Unless a statement is explicitly labelled **FACT**, no architecture or feature in this document is a confirmed design requirement.

## Known Starting Conditions

- **FACT:** The intended product is a tower-type system that moves ambient air through treatment stages and discharges treated air.
- **FACT:** The application environment is not finalized; indoor, semi-enclosed, and localized outdoor use remain possibilities.
- **FACT:** No airflow, CADR, pressure-drop, particle-removal, size, power, water, noise, or reliability target has been approved.
- **FACT:** HEPA, biochar or biomass-derived media, and a water stage are candidate concepts, not a validated treatment train.
- **ASSUMPTION:** The current team concept starts from a vertical package.
- **ASSUMPTION:** Two intake plus two exhaust fans is only an initial idea and is not treated as optimal.
- **UNKNOWN:** Which architecture best serves the eventual application and pollutant target.

## Concept A — Vertical Cross-Flow

### Name

Vertical Cross-Flow with Separate Clean-Air Riser

### Basic Idea

**ENGINEERING JUDGMENT:** Use a predominantly straight, horizontal flow path through flat, replaceable treatment cassettes. After treatment, collect the air in an isolated clean-side plenum or vertical riser and discharge it away from the intake.

### Conceptual Diagram

```text
DIRTY AIR
    |
    v
+----------+   +-------------+   +----------------+   +--------------+
|  INLET   |-->| DIRTY-AIR   |-->| INTERCHANGEABLE|-->| CLEAN-AIR    |
|  REGION  |   | PLENUM      |   | STAGE REGIONS  |   | RISER/PLENUM |
+----------+   +-------------+   +----------------+   +------+-------+
                                                               |
                                                        [FAN REGION?]
                                                               |
                                                               v
                                                        CLEAN EXHAUST
```

The stage regions are placeholders. Their order and even their inclusion remain **UNKNOWN**.

### Airflow Path

1. Ambient air enters a side or lower-side inlet.
2. A dirty-air plenum spreads the flow over the available treatment face.
3. Air crosses one or more flat, removable treatment regions.
4. A clean-side collection plenum receives the treated stream.
5. The flow turns into an isolated riser or discharge passage.
6. Air exits through a top, rear, or otherwise separated exhaust.

### Fan Location

**ENGINEERING JUDGMENT:** A clean-side extraction fan region is a useful first arrangement because it creates one main flow path and keeps the fan downstream of major particle filtration. Push-only or push-pull placements remain alternatives. Fan count and fan type are **UNKNOWN**.

### Intake Location

**ENGINEERING JUDGMENT:** A broad side or lower-side intake could expose a large flat filter area and simplify the dirty plenum. Required height, face area, guards, and weather protection are **UNKNOWN**.

### Exhaust Location

**ENGINEERING JUDGMENT:** A top or high rear exhaust separated from the inlet may reduce immediate short-circuiting. The safe separation and direction depend on the final application and must be tested.

### Filter Location

Flat cassettes could sit between the dirty and clean plenums. A prefilter, HEPA region, and adsorption region can be represented as independent removable placeholders; no sequence is selected.

### Water Stage

**UNKNOWN:** If retained, a water subsystem could occupy a separate upstream cassette or lower chamber with drainage, droplet containment, and demisting. It must not expose a dry filter or electrical region to uncontrolled moisture. A dry configuration that omits the water stage must remain possible.

### Expected Advantages

- **ENGINEERING JUDGMENT:** Simple, visible airflow path.
- **ENGINEERING JUDGMENT:** Flat filter panels may be easier to source, seal, replace, and represent in CAD.
- **ENGINEERING JUDGMENT:** Separate dirty and clean plenums support pressure measurements and staged testing.
- **ENGINEERING JUDGMENT:** Rectangular volumes should be straightforward for a first CFD model.
- **ENGINEERING JUDGMENT:** Service doors can potentially access each stage from one face.

### Potential Problems

- **UNKNOWN:** Flow may concentrate near the fan or turn, leaving parts of a filter underused.
- **UNKNOWN:** The clean-air riser and outlet turn may add pressure loss.
- **UNKNOWN:** Poor seals could allow bypass around flat cassettes.
- **UNKNOWN:** A side intake may be vulnerable to rain, impact, or obstruction in some applications.
- **UNKNOWN:** A wet stage could make the otherwise simple linear arrangement difficult to drain and isolate.

### Maintenance and Manufacturing

**ENGINEERING JUDGMENT:** Folded sheet panels or a simple frame with removable flat cassettes could make this the least complex architecture to fabricate. Clear acrylic or polycarbonate may be useful only for non-structural prototype viewing panels. A wet compartment, if used, should be a separately removable corrosion- and water-compatible module. Filter replacement, fan access, sensor taps, drains, and an isolated electrical access panel must be reachable without dismantling the whole tower.

### What CFD Must Determine

- How uniform is velocity across each treatment face?
- Does the inlet plenum need a diffuser, straightener, or baffle?
- Where do separation, recirculation, and dead zones form?
- How much loss comes from the inlet, each placeholder stage, the riser turn, and the outlet?
- Does extraction, intake, or push-pull fan placement improve the usable operating point?
- Is dirty-air or clean-air bypass likely at cassette edges?
- Is inlet-to-exhaust short-circuiting likely in the external flow field?

## Concept B — Central Core

### Name

Annular Intake with Central Clean-Air Core

### Basic Idea

**ENGINEERING JUDGMENT:** Admit air around much of the tower perimeter and draw it radially inward through concentric or segmented treatment media into a central clean-air core. Move the collected clean air vertically to an exhaust.

### Conceptual Diagram

```text
TOP VIEW

          AMBIENT AIR FROM MULTIPLE SIDES
              v       v       v
        +---------------------------+
        |  OUTER INTAKE / PLENUM    |
        |   +-------------------+   |
    --> |   | TREATMENT RING(S) |   | <--
        |   |     +-------+     |   |
    --> |   | --> | CLEAN | <-- |   | <--
        |   |     | CORE  |     |   |
        |   +-----+---+---+-----+   |
        +-------------|-------------+
                      |
                      v
              CENTRAL FAN REGION?
                      |
                      v
                 CLEAN EXHAUST
```

### Airflow Path

1. Ambient air enters around an outer perforated or segmented intake region.
2. An annular dirty-air space distributes flow around the perimeter.
3. Air moves radially inward through concentric or faceted treatment regions.
4. Treated air enters a central vertical clean-air core.
5. One or more fan regions move air along the core.
6. Air leaves through a separated upper exhaust.

### Fan Location

**ENGINEERING JUDGMENT:** A central clean-side extraction fan or stacked fan regions could create a compact pressure source. Distributed perimeter fans remain possible but would add wiring and balance questions. The arrangement is **UNKNOWN**.

### Intake Location

Intakes could cover a full circumference or selected perimeter sectors. **UNKNOWN:** A full circumference may not be suitable near walls, pedestrians, rain, or service panels.

### Exhaust Location

A vertical top exhaust aligns naturally with the central core. A side discharge would require another turn and separation from active intake sectors.

### Filter Location

Treatment media could form concentric cylinders, polygonal rings, or removable perimeter segments around the core. A prefilter could occupy the outermost accessible region; HEPA and adsorption media could occupy separate inner or outer dry segments, with their order left open. Curved HEPA or adsorption elements must not be assumed available; faceted standard cassettes may be more practical.

### Water Stage

**ENGINEERING JUDGMENT:** A wet annular stage would require a continuous or segmented collection basin below it, strong droplet containment, and a demister before any moisture-sensitive stage. Uniform spraying around a circumference is an important **UNKNOWN**. Omitting the water stage must remain an option.

### Expected Advantages

- **ENGINEERING JUDGMENT:** Large perimeter intake area may allow broad use of the tower surface.
- **ENGINEERING JUDGMENT:** Radial collection may create a compact central discharge path.
- **ENGINEERING JUDGMENT:** A central pressure source could reduce the number of separate fan stations.
- **ENGINEERING JUDGMENT:** Circumferential modularity may support adding or disabling intake sectors.

### Potential Problems

- **UNKNOWN:** Nonuniform resistance, blocked sectors, or nearby walls may cause strong circumferential imbalance.
- **UNKNOWN:** Sealing concentric or segmented media may be difficult.
- **UNKNOWN:** The inner core and rear sides of media may be hard to access.
- **UNKNOWN:** Curved parts, rings, and circular drains increase fabrication complexity.
- **UNKNOWN:** Central fan access may require removal of other components.
- **UNKNOWN:** A radial wet stage may create difficult drainage and demisting problems.

### Maintenance and Manufacturing

**ENGINEERING JUDGMENT:** A faceted polygon made from flat sheet-metal or polymer panels is more manufacturable than a fully curved shell, but the segmented seals and central-core support remain more complex than Concept A. Service doors must reach every perimeter segment, the core fan, sensors, drains, and electrical areas. Media cannot be treated as replaceable if inner segments cannot be removed safely.

### What CFD Must Determine

- How evenly does air enter around the perimeter under different surrounding obstructions?
- Does the central core draw excessively from the nearest or least-resistant sectors?
- What core size is needed to prevent high velocity and excess loss?
- Where do circumferential recirculation and axial imbalance occur?
- Can segmented media receive acceptably uniform face velocity?
- How do central versus distributed fans change flow balance?
- Does the external exhaust re-enter nearby intake sectors?
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

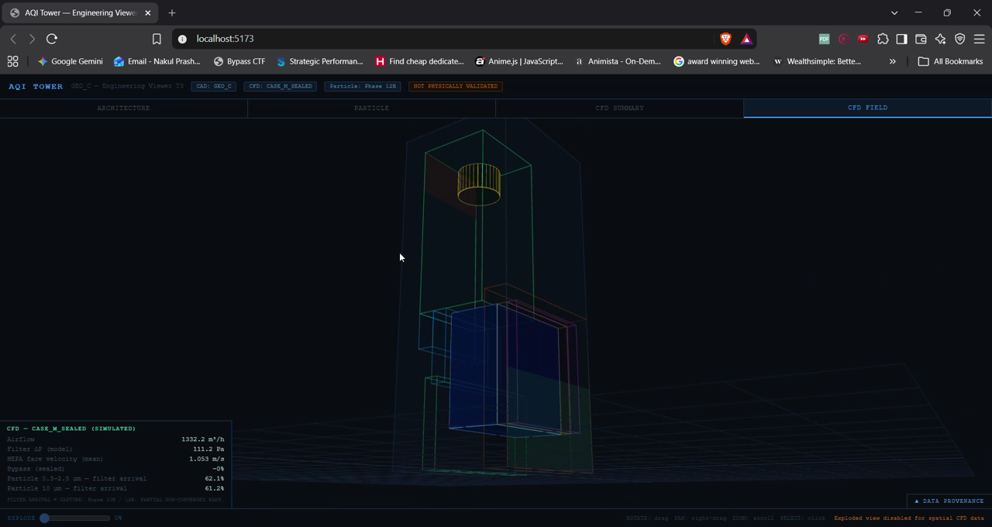
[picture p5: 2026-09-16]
reports/stakeholder_report/assets/cfd_table_a.png

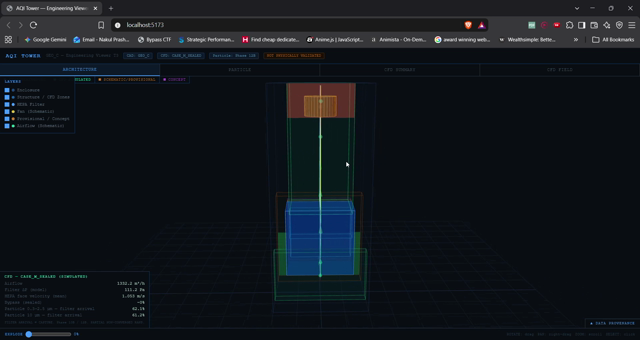
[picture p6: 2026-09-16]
reports/stakeholder_report/assets/threejs_04.png

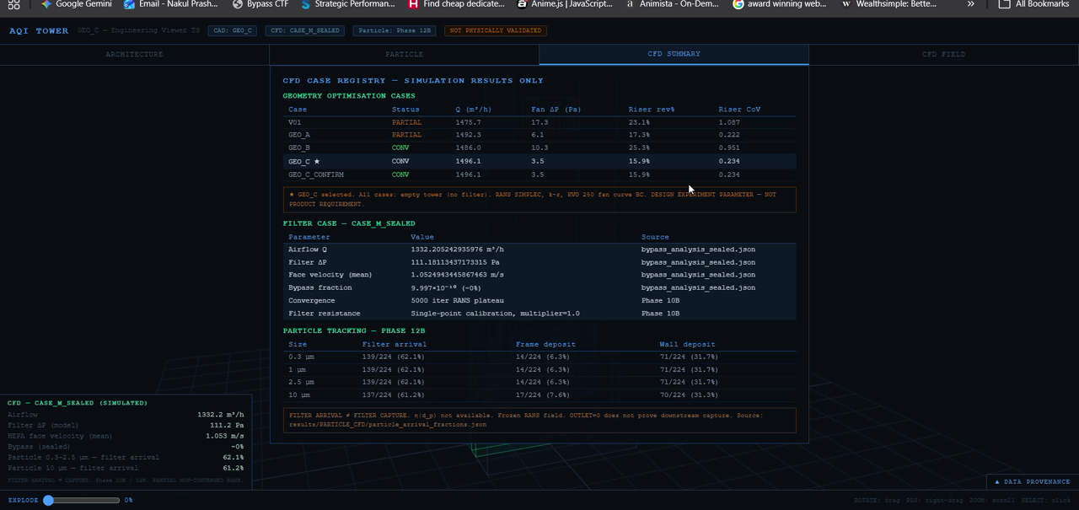
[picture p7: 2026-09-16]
reports/stakeholder_report/assets/cfd_summary_cropped.png

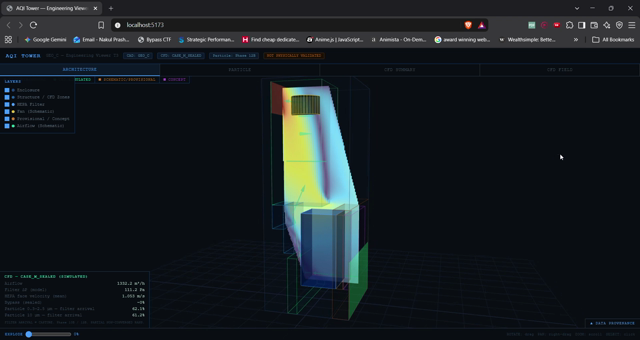
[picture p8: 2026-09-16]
reports/stakeholder_report/assets/threejs_02.png

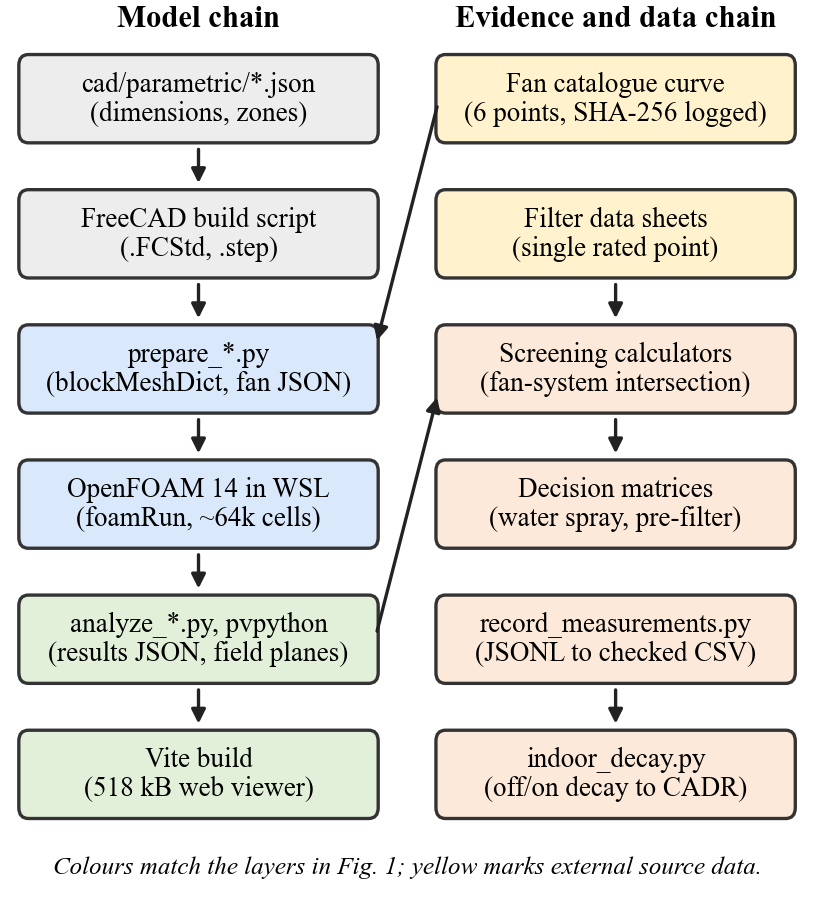
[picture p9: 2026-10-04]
docs/paper/figures/fig2_dataflow.png

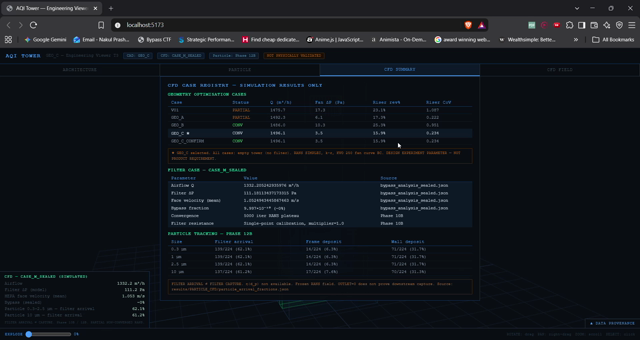
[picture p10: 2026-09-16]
reports/stakeholder_report/assets/main_07.png

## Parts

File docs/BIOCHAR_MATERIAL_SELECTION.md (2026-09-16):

# AQI Tower Phase 13 — Biochar Material Selection

**PHASE 13 — MATERIAL AND ADSORPTION EVIDENCE ONLY**  
**PHASE 13 HISTORICAL STATUS — TARGET GAS WAS NOT YET DEFINED**  
**PHASE 14 UPDATE — TARGET GAS: FORMALDEHYDE (HCHO); MATERIAL DECISION B**  
**BIOCHAR DATA STATUS: PARTIALLY READY**  
**No CFD run, CAD change, porous coefficient, or removal-performance claim**

## Purpose

The proposed carbon stage is intended for **pollutant-specific gas-phase adsorption**: selected volatile organic compounds (VOCs), organic vapors, or identified odor-causing gases. It is not a generic “AQI filter.” PM2.5 and PM10 remain particulate targets for the HEPA/prefilter system, not primary biochar targets.

An activated-carbon bed transfers gas molecules from air to a finite-capacity solid surface. Breakthrough occurs when the bed can no longer keep the downstream concentration below its selected limit. The US EPA therefore treats inlet/outlet VOC concentration, gas flow, temperature, relative humidity, pressure differential, and carbon activity as key performance indicators ([EPA carbon-adsorber guidance](https://www.epa.gov/air-emissions-monitoring-knowledge-base/monitoring-control-technique-activated-carbon-adsorber)).

### Material terms are not interchangeable

| Term | Meaning in this project | Engineering consequence |
|---|---|---|
| **BIOCHAR** | Biomass pyrolysis char without a demonstrated activation step for air adsorption | Properties can vary widely by feedstock and pyrolysis. It is not assumed to have activated-carbon pore structure or capacity. |
| **ACTIVATED CARBON** | Carbon intentionally activated by steam, CO₂, or a chemical route to develop adsorption pores | Can be an engineered granular or pelletized gas-phase medium if grade-specific data exist. |
| **ACTIVATED BIOCHAR** | Biomass-derived char given a documented post-activation or pore-development treatment | Research results apply only to that precursor and activation recipe. |
| **IMPREGNATED ADSORPTION MEDIA** | Activated carbon carrying reactive chemicals for a selected gas | Gas-specific chemistry, humidity response, heat release, compatibility, and disposal must be checked separately. |

The World Biochar Certificate defines biochar as biomass-derived porous carbon made by pyrolysis in low/no oxygen and notes that different applications require different quality characteristics ([WBC Guidelines v1.1](https://www.european-biochar.org/media/doc/2/wbc_1_1.pdf)). A peer-reviewed bamboo study likewise notes that ordinary biochar commonly has less-developed pore structure and that further physical or chemical activation produces material that is effectively activated carbon ([Rong et al., 2023](https://doi.org/10.1016/j.cej.2023.141979)).

## Candidate Materials

| Candidate | Required media distinction | Current evidence | Phase 13 role |
|---|---|---|---|
| Calgon Carbon OVC 4x8 | **C. Granulated activated carbon**, coconut shell, steam activated, non-impregnated | Manufacturer datasheet with particle specification and pressure-drop graph | **PRIMARY RESEARCH CANDIDATE** |
| Jacobi EcoSorb GX series | **C. Pelletized activated carbon**, exact grade not yet defined | Manufacturer family page; India plant/contact verified; no grade datasheet | **SECONDARY ALTERNATIVE**, conditional |
| Calgon Carbon FORMASORB | **E. Impregnated adsorption media**, coconut-shell activated carbon | Manufacturer datasheet; formaldehyde/aldehyde application; no pressure curve | **Phase 14 secondary formaldehyde-specific comparison**, conditional on exact-grade procurement and test evidence |
| SWP700 softwood-pellet biochar | **BIOCHAR**, no post-activation reported | Peer-reviewed benzene experiment | Research comparator only |
| RH550 rice-husk biochar | **A. Raw/research biochar**, no post-activation reported | Peer-reviewed MEK experiment | Research comparator only |
| R850 rice-husk activated carbon | **D. Activated biochar / biomass-derived activated carbon**, CO₂ activated | Peer-reviewed 16-VOC humidity experiment | Research comparator only |
| Bamboo BPGC | **D. Activated/modified biochar**, KOH-assisted catalytic graphitization | Peer-reviewed VOC and humidity results | Advanced research option, not procurement-ready |

## Pollutant Targets

**PHASE 14 SUPERSEDING DECISION: TARGET GAS — FORMALDEHYDE (HCHO / CH₂O, CAS 50-00-0).**

The Phase 13 statement that the target was not yet defined is retained as historical context. Phase 14 independently compared six candidates and froze HCHO. See [`PHASE14_FORMALDEHYDE_TARGET.md`](PHASE14_FORMALDEHYDE_TARGET.md) for concentrations, breakthrough definitions, safety, measurement, and experiment requirements.

The system requirement must name a compound or controlled mixture before adsorption performance can be designed. “VOC” is a class, not a single adsorbate. Evidence for benzene cannot be transferred to formaldehyde, MEK, H₂S, NO₂, ozone, or another gas.

Candidate target families for requirements work are:

- Non-polar organic vapors such as toluene or similar solvent vapors, for which non-impregnated microporous activated carbon may be relevant.
- Polar/small organic gases such as formaldehyde, which ordinary activated carbon may adsorb poorly and which can require specialized impregnated media. The EPA specifically identifies formaldehyde and methanol among compounds for which ordinary activated carbon can be less effective ([EPA Carbon Adsorbers chapter](https://www.epa.gov/sites/default/files/2018-10/documents/final_carbonadsorberschapter_7thedition.pdf)).
- Identified odor gases such as H₂S, mercaptans, or amines, which often require pollutant-specific impregnated or catalytic media rather than generic GAC.

NOx, SOx, CO, and ozone are not assigned to the carbon stage without species-specific evidence and an explicit requirement.

## Material Properties

| Candidate | Precursor and process | Surface area | Particle form | Bulk density | Pore information |
|---|---|---:|---|---:|---|
| OVC 4x8 | Coconut shell; high-temperature steam activation | NOT AVAILABLE | 4x8 US mesh, nominal range bounded by 4.75 and 2.36 mm screens | NOT AVAILABLE | High surface area/fine pores stated; no numeric distribution |
| FORMASORB | Coconut shell; steam activation plus impregnation | 1150 m²/g typical | 4x8 or 6x12 mesh | 600 kg/m³ typical | Numeric distribution NOT AVAILABLE |
| EcoSorb GX | Exact precursor/process NOT AVAILABLE | NOT AVAILABLE | Extruded pellet; diameter NOT AVAILABLE | NOT AVAILABLE | NOT AVAILABLE |
| SWP700 | Softwood pellets; pyrolysis at 700 °C | NOT AVAILABLE in accessible record | Final bed form NOT AVAILABLE | NOT AVAILABLE | NOT AVAILABLE |
| RH550 | Rice husk; pyrolysis at 550 °C | NOT AVAILABLE in accessible record | NOT AVAILABLE | NOT AVAILABLE | NOT AVAILABLE |
| R850 | Rice husk; carbonization + CO₂ activation at 850 °C | Numeric value NOT AVAILABLE in accessible record | NOT AVAILABLE | NOT AVAILABLE | Study identifies the highest surface/micropore area among its three samples |
| Bamboo BPGC | Bamboo; KOH-promoted nickel-catalyzed graphitization | 2181 m²/g | NOT AVAILABLE | NOT AVAILABLE | Micro-mesoporous; O/C = 0.038 |

Sources: [OVC 4x8 datasheet](https://www.calgoncarbon.com/app/uploads/DS-OVC4x815-EIN-E2.pdf), [FORMASORB datasheet](https://www.calgoncarbon.com/app/uploads/FORMASORB.pdf), [Jacobi product families](https://www.jacobi.net/products/), and the peer-reviewed papers recorded below.

## Adsorption Evidence

### Manufacturer/product evidence

- **OVC 4x8:** Calgon Carbon identifies it for vapor-phase VOC and odor removal and specifies carbon-tetrachloride activity of at least 60 wt%. That activity number is a standardized vapor-capacity indicator, not a removal percentage for the AQI Tower or for an unspecified VOC ([manufacturer datasheet](https://www.calgoncarbon.com/app/uploads/DS-OVC4x815-EIN-E2.pdf)). No compound-specific breakthrough curve was found.
- **FORMASORB:** the manufacturer identifies formaldehyde and other aldehydes as targets. The datasheet gives surface area, bulk density, mesh sizes, and a general gas-capacity specification, but no formaldehyde breakthrough capacity under tower conditions ([manufacturer datasheet](https://www.calgoncarbon.com/app/uploads/FORMASORB.pdf)).
- **EcoSorb GX:** Jacobi describes the GX series as extruded pellet carbon for general air treatment, but the public family page does not provide an exact grade or quantitative adsorption dataset ([Jacobi products](https://www.jacobi.net/products/)).

### Peer-reviewed experimental records

| Paper | Material and activation | Pollutant and test conditions | Reported result | Transfer limit |
|---|---|---|---|---|
| *Adsorption performance of standard biochar materials against volatile organic compounds in air: A case study using benzene and methyl ethyl ketone* — Kumar Vikrant, Ki-Hyun Kim, Wanxi Peng, Shengbo Ge, Yong Sik Ok (2020), DOI [10.1016/j.cej.2019.123943](https://doi.org/10.1016/j.cej.2019.123943) | 12 standard biochars from six feedstocks; 550 and 700 °C pyrolysis; no activation reported | Benzene and MEK at 1 Pa each; other mass, humidity, contact-time, and duration fields not available in the accessible record | Highest benzene capacity: SWP700, 2.9 mg/g. Highest MEK capacity: RH550, 43 mg/g. | Two specific gases and research chars; no packed-bed pressure loss or commercial specification |
| *Biochar for volatile organic compound (VOC) removal: Sorption performance and governing mechanisms* — Xueyang Zhang, Bin Gao, Yulin Zheng, Xin Hu, Anne Elise Creamer, Michael D. Annable, Yuncong Li (2017), DOI [10.1016/j.biortech.2017.09.025](https://doi.org/10.1016/j.biortech.2017.09.025) | 15 biochars, five feedstocks, pyrolyzed at 300/450/600 °C | Acetone, cyclohexane, toluene; gas-phase sorption; detailed concentration/mass/humidity unavailable in accessible abstract | Overall capacities 5.58–91.2 mg/g; both adsorption and partitioning mattered; performance retained through five sorption/desorption cycles | Wide variation demonstrates that “raw biochar” is not one reproducible medium |
| *Adsorption of volatile organic vapors by activated carbon derived from rice husk under various humidity conditions...* — Mei-Syue Li, Siang-Chen Wu, Yu-Huei Peng, Yang-Hsin Shih (2016), DOI [10.1016/j.seppur.2016.06.029](https://doi.org/10.1016/j.seppur.2016.06.029) | Rice-husk R850 activated carbon; carbonization then CO₂ activation at 1123 K | 16 VOCs by inverse gas chromatography at about 55% and 90% RH; mass/EBCT/duration unavailable in accessible record | log Kd reported as 4.0–6.1 at about 55% RH and decreased at 90% RH | Research sample, not a commercial packed bed; humidity effect is relevant but compound-specific values are needed |
| *Production of Activated Biochar Derived from Residual Biomass for Adsorption of Volatile Organic Compounds* — Elena David (2023), DOI [10.3390/ma16010389](https://doi.org/10.3390/ma16010389) | Rapeseed-cake and walnut-shell chars; KOH or H₂SO₄ treatment plus 800 °C; particles ≤1 mm | 1000 ppm toluene or acetone in N₂, 50 mL/min, about 20 °C, approximately 15 mg sample, 15 min; triplicate tests | Raw chars 16.76–26.65 mg/g; activated variants 51.28–166.72 mg/g depending on precursor/activation/VOC | Fine laboratory material; no bed pressure, humidity series, or commercial manufacturability demonstrated |
| *Bamboo-derived hydrophobic porous graphitized carbon for adsorption of volatile organic compounds* — Yang Rong, Cong Pan, Kexin Song, Jong Chol Nam, Feng Wu, Zhixiong You, Zhengping Hao, Jinjun Li, Zhongshen Zhang (2023), DOI [10.1016/j.cej.2023.141979](https://doi.org/10.1016/j.cej.2023.141979) | Bamboo-derived micro-mesoporous graphitized carbon, KOH-assisted nickel-catalyzed route | Toluene, cyclohexane, ethanol under dry and 80% RH conditions; accessible record does not provide flow, concentration, mass, EBCT, or duration | Dry capacities 6.7, 3.8, and 2.4 mmol/g; at 80% RH, toluene and cyclohexane retained 82% and 66% of dry capacity; ethanol uptake rose 33% | Advanced synthesis, no pressure-loss data, India supply, scale-up, or nickel-management plan |

Laboratory capacities are not guaranteed removal percentages. They cannot be transferred across gases, concentrations, relative humidities, flow rates, bed sizes, or media production routes.

## Pressure-Drop Evidence

Only OVC 4x8 currently has candidate-specific pressure-loss information:

- The official OVC datasheet contains a **typical pressure-drop graph** for 4x8 granular carbon at 70 °F and 15 psia, with loose/dense packing context. Calgon instructs designers to use dense-packed pressure loss because the bed settles in service ([OVC 4x8 datasheet](https://www.calgoncarbon.com/app/uploads/DS-OVC4x815-EIN-E2.pdf)).
- The graph is not tabulated. No points or coefficients were digitized in Phase 13.
- The plotted superficial-velocity range ends near 110 ft/min, approximately 0.56 m/s. If a carbon bed used the current 0.3516 m² filter-face area, the existing modelled face velocity would be 1.053 m/s—outside the graph range. Extrapolation is not defensible.
- OVC bulk density and bed void fraction are absent from the retrieved datasheet, preventing a fully parameterized Ergun model.

For FORMASORB, EcoSorb GX, SWP700, RH550, R850, and bamboo BPGC:

**NOT AVAILABLE — REQUIRES EXPERIMENT.**

The International Activated Carbon industry test method describes pressure drop as a function of gas velocity and reports it per unit bed length, using a packed column and multiple measured flow points ([industry test method](https://www.activatedcarbon.org/wp-content/uploads/2025/02/Test_method_for_Activated_Carbon_86.pdf)). This is the appropriate basis for the proposed bench test.

## Moisture Considerations

Humidity is a first-order design variable, not a footnote:

- EPA guidance states that water competes for activated-carbon adsorption sites and that high relative humidity can reduce capacity; small/polar VOCs can be especially difficult for ordinary carbon ([EPA Carbon Adsorbers chapter](https://www.epa.gov/sites/default/files/2018-10/documents/final_carbonadsorberschapter_7thedition.pdf)).
- The R850 rice-husk experiment observed lower adsorption coefficients when RH increased from approximately 55% to 90% ([Li et al., 2016](https://doi.org/10.1016/j.seppur.2016.06.029)).
- The bamboo BPGC study demonstrated better—but not complete—capacity retention for selected non-polar VOCs at 80% RH ([Rong et al., 2023](https://doi.org/10.1016/j.cej.2023.141979)).
- An impregnated medium may respond differently because water can participate in or inhibit its chemistry. No generic humidity correction is permitted.

If the proposed water stage is ever placed upstream of an adsorption bed, moisture carryover would require independent validation. No stage order is selected in Phase 13.

## Manufacturing Considerations

- **OVC 4x8 GAC:** controlled granule distribution, high hardness (97 minimum), low ash (3 wt% maximum), and thermal-reactivation statement support repeatable handling. A screen/support layer, dust containment, seal, and service cassette would still be required in a future design.
- **Pelletized activated carbon:** an exact Jacobi EcoSorb GX grade could offer consistent geometry, but no pressure-loss advantage is assumed until a datasheet or test confirms it.
- **Raw biochar:** feedstock identity and pyrolysis temperature are insufficient specifications. Batch quality would also require particle-size distribution, ash, volatiles, moisture, bulk density, surface area/pore distribution, dust generation, contaminants, and gas-specific breakthrough testing.
- **Activated/modified biochar:** KOH, acid, or nickel-assisted routes introduce washing, residual-chemical, wastewater, corrosion, worker-safety, and quality-control requirements. These are not suitable for informal student manufacture without institutional laboratory procedures.
- **Safety:** the OVC manufacturer warns that wet activated carbon can deplete oxygen in enclosed spaces. Carbon dust and combustible media require sealed handling, ventilation, ignition control, PPE, and appropriate supervision ([OVC safety statement](https://www.calgoncarbon.com/app/uploads/DS-OVC4x815-EIN-E2.pdf)).

## Availability

| Candidate | India status | Cost status |
|---|---|---|
| OVC 4x8 / FORMASORB | Kuraray lists activated carbon in India and identifies Calgon Carbon India LLP, but the exact grades, stock, MOQ, lead time, and reactivation service are **NOT CONFIRMED** ([Kuraray India product search](https://www.kuraray.com/in-en/products/search_name/), [Kuraray group entity list](https://www.kuraray.com/customer-privacy-notice/en/list_en.pdf)) | NO RELIABLE CURRENT PRICE — QUOTE REQUIRED |
| Jacobi EcoSorb GX | Jacobi operates an activated-carbon manufacturing plant and office in Coimbatore/Pollachi, but exact GX availability is **NOT CONFIRMED** ([Jacobi India contact](https://services.jacobi.net/contact/)) | NO RELIABLE CURRENT PRICE — QUOTE REQUIRED |
| Research biochars / activated biochars | No consistent air-treatment-grade Indian product matching the study recipes was verified | NOT AVAILABLE |

Do not treat generic e-commerce “activated charcoal” or soil biochar as an engineering substitute for a traceable air-treatment grade.

## Primary Candidate

### PRIMARY RESEARCH CANDIDATE

**Calgon Carbon OVC 4x8 — non-impregnated steam-activated coconut-shell GAC.**

Selection reasons:

1. Exact vapor-phase product identity and manufacturer datasheet.
2. Controlled 4x8 granule size and high hardness.
3. Official pressure-drop graph, including a dense-pack design instruction.
4. Suitable as a neutral benchmark before a pollutant-specific impregnated chemistry is selected.
5. Manufacturer states thermal reactivation is possible.

This is a **research selection only**. It is not final because target gas, product-specific breakthrough capacity, tower-range pressure loss, local lot availability, cost, bed depth, and safety/service arrangements remain unresolved.

## Alternative Candidate

### SECONDARY ALTERNATIVE

**Jacobi EcoSorb GX-series extruded activated carbon**, conditional on Jacobi Carbons India identifying an exact grade and providing:

- grade-specific precursor and activation route;
- pellet diameter and size distribution;
- surface area, bulk density, hardness, ash, and moisture;
- compound-specific adsorption/breakthrough data;
- pressure drop versus superficial velocity and bed depth;
- SDS, price, MOQ, lead time, and reactivation/disposal route.

**Phase 14 secondary comparison:** FORMASORB is now the formaldehyde-specific comparison material, conditional on exact-grade procurement, SDS, pressure testing, and matched HCHO breakthrough testing. It does not replace OVC 4×8 automatically.

## Data Gaps

1. **TARGET GAS RESOLVED IN PHASE 14: FORMALDEHYDE.** Final media suitability is still unknown until matched HCHO testing is complete.
2. Phase 14 now defines inlet concentrations, normalized outlet/breakthrough states, temperature, and RH. Real mixed-contaminant exposure and required service hours remain unknown.
3. No candidate has a product-specific breakthrough curve at AQI Tower conditions.
4. The OVC pressure graph is not tabulated and does not cover the existing 1.053 m/s face velocity.
5. Bulk density and void fraction are missing for OVC; exact properties are missing for EcoSorb GX.
6. Bed face area, depth, mass, packing procedure, and allowable pressure drop are requirements, not yet values.
7. India stock, exact grade, minimum order, lead time, price, sample availability, and spent-media service are unconfirmed.
8. Humidity sensitivity is unmeasured for the commercial candidates.
9. Dust release, ignition risk, off-gassing, contaminants, seal integrity, maintenance, and disposal are untested.
10. No adsorption percentage, service life, or integrated-system performance is established.

### Source-quality audit

| Evidence level | Sources used | Engineering use |
|---|---|---|
| A | OVC 4x8 and FORMASORB manufacturer datasheets | Product identity and listed physical/test properties only |
| B | Five peer-reviewed gas-phase adsorption studies | Mechanism, material-specific capacity, and humidity evidence under their stated experiments |
| C | EPA guidance, World Biochar Certificate, activated-carbon industry pressure-drop method, manufacturer family/contact pages | Definitions, test planning, safety, and availability channels |
| D | No D-level source used for a design value | Discovery only; excluded from engineering data |

Research stopped when each required evidence slot had either a primary/peer-reviewed source or an explicit gap. Additional generic supplier claims would not resolve the decisive missing items: named target gas, exact locally supplied grade, tower-range pressure loss, and matched-condition breakthrough data.

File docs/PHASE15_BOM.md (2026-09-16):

# AQI Tower Phase 15 — Bill of Materials and Procurement Table

**PHASE 15 — PROCUREMENT PLANNING ONLY**
**STATUS: SPECIFICATION DOCUMENT — NO PURCHASE MADE**
**Date: 2026-09-06**

All items are classified by procurement status:
- **VERIFIED PRODUCT** — confirmed to exist with cited evidence and example price
- **CANDIDATE PRODUCT** — believed to be available; price indicative, not a quote
- **GENERIC REQUIREMENT** — functional specification only; specific product not selected
- **REQUIRES QUOTE** — specification is clear but current India price/availability not confirmed
- **UNKNOWN** — availability and price both require investigation

India prices where stated are observed single-distributor listings on the stated date; they are not procurement commitments and do not include GST, shipping, or import duty unless noted. Prices marked as volatile or observed may have changed.

---

## Category 1 — Column and Pressure Hardware

| # | Item | Specification | Example product / vendor | Evidence | Qty | Priority | Est. cost | Status |
|---|---|---|---|---|---|---|---|---|
| 1.1 | Test column body | SS316 tube, 75 mm ID, ≥ 200 mm length, flanged ends; or equivalent borosilicate glass chromatography column | Custom SS fabrication (local workshop) or Sigma-Aldrich chromatography column 65 mm–75 mm ID | GENERIC REQUIREMENT | 1 | MUST BUY | REQUIRES QUOTE | GENERIC REQUIREMENT |
| 1.2 | Flanged end caps (pair) | SS316, 75 mm bore, flat or dished; drilled for 1/8" NPT sample port + pressure tap | Local SS fabrication | GENERIC REQUIREMENT | 2 | MUST BUY | REQUIRES QUOTE | GENERIC REQUIREMENT |
| 1.3 | SS316 retaining screens | 2.0 mm opening woven wire mesh, 75 mm diameter discs | Scientific mesh suppliers India (IndiaMART: woven wire mesh discs) | CANDIDATE PRODUCT | 6 | MUST BUY | REQUIRES QUOTE | CANDIDATE PRODUCT |
| 1.4 | Inlet distributor / perforated plate | SS316 perforated plate ≥ 30% open area, 75 mm disc, or sintered SS disc | Local fabrication or SS perforated sheet cut to disc | GENERIC REQUIREMENT | 2 | MUST BUY | REQUIRES QUOTE | GENERIC REQUIREMENT |
| 1.5 | PTFE sheet gaskets | 1–2 mm flat PTFE for flange seals | Standard industrial PTFE sheet, cut to flange size | CANDIDATE PRODUCT | 1 sheet | MUST BUY | ~₹500–1,000 | CANDIDATE PRODUCT |
| 1.6 | Differential pressure sensor | 0–500 Pa range, ≤1 Pa resolution, I²C or 4–20 mA output, SS or PTFE wetted parts | Sensirion SDP510 (+500 Pa, I²C) — CANDIDATE; or Honeywell HSC series — CANDIDATE | Sensirion product page; RS Components | 1 (2 preferred) | MUST BUY | REQUIRES QUOTE | CANDIDATE PRODUCT |
| 1.7 | DP sensor reference / check manometer | Inclined water manometer or calibrated digital reference, 0–500 Pa | Laboratory equipment supplier | GENERIC REQUIREMENT | 1 | MUST BUY | REQUIRES QUOTE | GENERIC REQUIREMENT |
| 1.8 | Pressure tap tubing | 3 mm OD SS or PTFE, 500 mm lengths | Standard SS/PTFE tubing, India suppliers | CANDIDATE PRODUCT | 2 lengths | MUST BUY | ~₹200–500 | CANDIDATE PRODUCT |
| 1.9 | Column stand / clamp | Lab retort stand + column clamps, vertical mounting | Standard lab equipment | GENERIC REQUIREMENT | 1 set | MUST BUY | ~₹500–1,500 | GENERIC REQUIREMENT |

**Fabrication note:** For the minimum viable tier, a transparent acrylic column body (ID = 75 mm) can be fabricated from acrylic tube stock by a local plastics supplier. Acrylic has known HCHO adsorption at low ppb; acceptable for pressure-drop (clean air) tests but must NOT be used for breakthrough tests with HCHO unless a blank test confirms negligible uptake under the test conditions. For breakthrough tests, SS316 or borosilicate glass is required.

---

## Category 2 — Flow Measurement and Control

| # | Item | Specification | Example product / vendor | Evidence | Qty | Priority | Est. cost | Status |
|---|---|---|---|---|---|---|---|---|
| 2.1 | Rotameter, 0–100 L/min air | Acrylic float, scale in L/min, needle valve at inlet, ±3% FS accuracy | Shree Aashapura Instrument, Mumbai, IndiaMART | IndiaMART listing observed ₹1,950 | 1 | MUST BUY | ~₹1,950 | CANDIDATE PRODUCT |
| 2.2 | Rotameter, 0–300 L/min air | Acrylic or SS float, for U_s = 0.52–1.05 m/s at 75 mm column | IndiaMART vendors; Deluxe Gases Pune | IndiaMART listings | 1 | MUST BUY | REQUIRES QUOTE | CANDIDATE PRODUCT |
| 2.3 | Needle valves (SS) | 1/4" or 3/8" NPT SS, fine adjustment; one per rotameter | Industrial valves, IndiaMART | CANDIDATE PRODUCT | 2 | MUST BUY | ~₹300–800 each | CANDIDATE PRODUCT |
| 2.4 | MFC, zero air, 0–80 L/min | Thermal mass flow controller, air, calibrated ±1% FS, for breakthrough tests | Alicat MC-50SLPM or 100SLPM, Bronkhorst EL-FLOW | International; India distributor UNKNOWN | 1 | RECOMMENDED | REQUIRES QUOTE | REQUIRES QUOTE |
| 2.5 | MFC, standard gas, 0–2 L/min | Thermal MFC, N₂ or air, calibrated ±1% FS, for HCHO cylinder dilution | Alicat MC-2SLPM, Bronkhorst | International; India distributor UNKNOWN | 1 | RECOMMENDED | REQUIRES QUOTE | REQUIRES QUOTE |
| 2.6 | Air compressor or lab bench supply | Oil-free compressor, ≥ 300 L/min at 2 bar; or lab building compressed air line | Local supplier; facility | GENERIC REQUIREMENT | 1 | MUST BUY or BORROW | Facility dependent | GENERIC REQUIREMENT |
| 2.7 | Air treatment (for zero air) | Activated carbon trap + molecular sieve (4A) + particulate filter, inline; verify HCHO blank < 5 µg/m³ | Gas filtration components, scientific supplier | GENERIC REQUIREMENT | 1 set | MUST BUY | REQUIRES QUOTE | GENERIC REQUIREMENT |

---

## Category 3 — HCHO Sensing

| # | Item | Specification | Example product / vendor | Evidence | Qty | Priority | Est. cost | Status |
|---|---|---|---|---|---|---|---|---|
| 3.1 | Sensirion SFA30-D-T module | 0–1000 ppb HCHO, I²C/UART, integrated T/RH, 3.3 V | E Control Devices India | ₹7,099 observed (one distributor, 2026-09-06) | 3 (2 active + 1 spare) | MUST BUY | ~₹21,300 | CANDIDATE PRODUCT |
| 3.2 | SFA30 breakout board / adapter | ZIF connector breakout for 7-pin SFA30 connector; or use SparkFun SEN-17228 | SparkFun (international) or custom PCB | SparkFun product page | 2 | MUST BUY | ~$10–15 USD each + import | CANDIDATE PRODUCT |
| 3.3 | 3.3 V power supply | Regulated 3.3 V, ≥ 200 mA; USB or linear regulator module | Standard electronics component | CANDIDATE PRODUCT | 2 | MUST BUY | ~₹50–200 each | CANDIDATE PRODUCT |
| 3.4 | I²C interface wiring | 100 mm–500 mm shielded cables; PTFE-insulated preferred | Standard electronics component | GENERIC REQUIREMENT | 1 set | MUST BUY | ~₹200 | GENERIC REQUIREMENT |

---

## Category 4 — HCHO Reference Analysis (DNPH / HPLC)

| # | Item | Specification | Example product / vendor | Evidence | Qty | Priority | Est. cost | Status |
|---|---|---|---|---|---|---|---|---|
| 4.1 | DNPH sampling cartridges | DNPH-coated silica, Sep-Pak type or Supelco LpDNPH S10; store refrigerated, protected from light | Waters, Sigma-Aldrich India, HiMedia | Sigma-Aldrich US listed; India UNKNOWN | 20 minimum per campaign | MUST BUY | REQUIRES QUOTE | CANDIDATE PRODUCT |
| 4.2 | Sampling pump (personal air) | Constant-flow pump 0.5–2 L/min, ±2% calibrated; compatible with HCHO environment | SKC Pocket Pump, Gillian BDX-II, or equivalent | CANDIDATE PRODUCT | 2 | MUST BUY | REQUIRES QUOTE | CANDIDATE PRODUCT |
| 4.3 | Rotameter for DNPH pump calibration | Calibrated bubble/electronic soap-film flowmeter or calibration rotameter | DryCal or similar | CANDIDATE PRODUCT | 1 | MUST BUY | REQUIRES QUOTE | CANDIDATE PRODUCT |
| 4.4 | Sample vials (amber glass) | 2 mL amber HPLC vials + caps; PTFE-lined caps | Standard laboratory supply, HiMedia India | CANDIDATE PRODUCT | 50 per campaign | MUST BUY | ~₹5–15 each | CANDIDATE PRODUCT |
| 4.5 | External HPLC analysis service | ISO/IEC 17025 accredited carbonyl analysis; formaldehyde-DNPH by HPLC/UV; report µg/m³ + expanded uncertainty | NABL-accredited lab; e.g., Bureau Veritas India, CSIR-NEERI collaboration | REQUIRES QUOTE; institutional collaboration preferred | Per campaign | BORROW / OUTSOURCE | REQUIRES QUOTE | REQUIRES QUOTE |

---

## Category 5 — T/RH Measurement

| # | Item | Specification | Example product / vendor | Evidence | Qty | Priority | Est. cost | Status |
|---|---|---|---|---|---|---|---|---|
| 5.1 | SFA30 integrated T/RH | Provided by the SFA30 module (see Category 3) | — | Sensirion DS v1.3 | — | INCLUDED | See Cat. 3 | VERIFIED PRODUCT |
| 5.2 | Reference T/RH probe (stress tests only) | Calibrated probe ±0.5°C / ±2% RH; e.g., E+E EE33, Vaisala HMP series | E+E Elektronik India Private Limited | India presence confirmed (IndiaMART) | 1 | RECOMMENDED | REQUIRES QUOTE | CANDIDATE PRODUCT |

---

## Category 6 — HCHO Generation System

| # | Item | Specification | Example product / vendor | Evidence | Qty | Priority | Est. cost | Status |
|---|---|---|---|---|---|---|---|---|
| 6.1 | HCHO certified gas cylinder | 5–50 ppm HCHO in zero air or N₂; NIST/NPL-traceable; ±2% certified | BOC India, Linde India, NCL Pune | REQUIRES QUOTE | 1 | MUST BUY (for breakthrough) | REQUIRES QUOTE | REQUIRES QUOTE |
| 6.2 | Cylinder regulator (SS diaphragm) | SS two-stage regulator for HCHO gas; PTFE seat; 0–2 bar outlet | Matheson or equivalent | GENERIC REQUIREMENT | 1 | MUST BUY (for breakthrough) | REQUIRES QUOTE | GENERIC REQUIREMENT |
| 6.3 | MFCs | See Category 2, items 2.4 and 2.5 | — | — | — | RECOMMENDED | REQUIRES QUOTE | REQUIRES QUOTE |
| 6.4 | Static mixer | 150 mm SS or PTFE tube with turbulence inserts | Lab fabrication or inline mixer supplier | GENERIC REQUIREMENT | 1 | MUST BUY | REQUIRES QUOTE | GENERIC REQUIREMENT |
| 6.5 | Humidifier | Nafion membrane humidifier or SS bubbler; delivers controlled RH to carrier air | Perma Pure Nafion or equivalent; India availability UNKNOWN | CANDIDATE PRODUCT | 1 | MUST BUY (for breakthrough) | REQUIRES QUOTE | REQUIRES QUOTE |
| 6.6 | HCHO exhaust scrubber | Carbon scrubber or KMnO₄ scrubber rated for HCHO; or routed to institution fume-hood exhaust | Institutional facility (preferred) or Purafil CC media | GENERIC REQUIREMENT | 1 | MUST BUY | Facility dependent | GENERIC REQUIREMENT |
| 6.7 | Area HCHO safety monitor | Independent calibrated HCHO monitor; alarm ≤ 0.05 ppm; not the SFA30 | Dräger Pac 7000, RAE Systems, or equivalent | CANDIDATE PRODUCT | 1 | MUST BUY | REQUIRES QUOTE | CANDIDATE PRODUCT |

---

## Category 7 — Tubing and Fittings

| # | Item | Specification | Example product / vendor | Evidence | Qty | Priority | Est. cost | Status |
|---|---|---|---|---|---|---|---|---|
| 7.1 | PTFE tubing | 6 mm OD × 4 mm ID PTFE; all wetted lines downstream of HCHO injection | SS/PTFE supplier IndiaMART, Pune | CANDIDATE PRODUCT | 5 m | MUST BUY | ~₹200–500/m | CANDIDATE PRODUCT |
| 7.2 | SS316 tubing (upstream) | 6 mm OD SS316 for lines that may contact HCHO | Industrial tube supplier | CANDIDATE PRODUCT | 2 m | MUST BUY | REQUIRES QUOTE | CANDIDATE PRODUCT |
| 7.3 | PTFE or SS compression fittings | 6 mm Swagelok-type or Parker A-Lok, SS316 | Swagelok India (Mumbai, Pune offices) | CANDIDATE PRODUCT | 20 | MUST BUY | REQUIRES QUOTE | CANDIDATE PRODUCT |
| 7.4 | T-fittings (PTFE or SS) | 6 mm three-way T for sample-port branches | Swagelok India or equivalent | CANDIDATE PRODUCT | 4 | MUST BUY | REQUIRES QUOTE | CANDIDATE PRODUCT |
| 7.5 | Ball valves (SS, PTFE seat) | 1/4" SS ball valve with PTFE seat for bypass / isolation | Industrial valve supplier, IndiaMART | CANDIDATE PRODUCT | 4 | MUST BUY | ~₹300–600 each | CANDIDATE PRODUCT |

---

## Category 8 — Data Acquisition and Logging

| # | Item | Specification | Example product / vendor | Evidence | Qty | Priority | Est. cost | Status |
|---|---|---|---|---|---|---|---|---|
| 8.1 | Raspberry Pi 4B (or equivalent) | Linux SBC, I²C + UART capable, USB; runs Python logging script | Raspberry Pi Foundation; available at Robu.in, Evelta India | CANDIDATE PRODUCT | 1 | MUST BUY | ~₹5,000–7,000 | CANDIDATE PRODUCT |
| 8.2 | I²C multiplexer (TCA9548A) | Allows two SFA30s on same I²C bus (different addresses possible; check SFA30 address config) | Adafruit, Robu.in | CANDIDATE PRODUCT | 1 | MUST BUY | ~₹200–400 | CANDIDATE PRODUCT |
| 8.3 | Analog-to-digital converter (for DP sensor) | 16-bit ADC if DP sensor has analog output (4–20 mA → voltage divider) | ADS1115 or similar, Robu.in | CANDIDATE PRODUCT | 1 | MUST BUY | ~₹150–400 | CANDIDATE PRODUCT |
| 8.4 | Real-time clock module | Battery-backed RTC (DS3231) for accurate timestamping | Robu.in, Amazon.in | CANDIDATE PRODUCT | 1 | MUST BUY | ~₹100–300 | CANDIDATE PRODUCT |
| 8.5 | SD card for local logging | 32 GB microSD, class 10 | Standard | CANDIDATE PRODUCT | 2 | MUST BUY | ~₹300–500 | CANDIDATE PRODUCT |
| 8.6 | USB keyboard and monitor | For Raspberry Pi setup; not required for headless operation | Standard | GENERIC REQUIREMENT | — | CAN BORROW | — | GENERIC REQUIREMENT |
| 8.7 | Enclosure (IP54 or better) | Protects DAQ electronics from laboratory humidity | ABS enclosure, IndiaMART | CANDIDATE PRODUCT | 1 | RECOMMENDED | ~₹300–800 | CANDIDATE PRODUCT |

---

## Category 9 — Activated Carbon Media

| # | Item | Specification | Example product / vendor | Evidence | Qty | Priority | Est. cost | Status |
|---|---|---|---|---|---|---|---|---|
| 9.1 | Calgon Carbon OVC 4×8 | Steam-activated coconut-shell GAC; 4×8 US mesh; min. CTC activity 60; lot certificate and SDS required | Kuraray/Calgon Carbon India (Calgon Carbon India LLP) | Kuraray India presence confirmed; exact OVC 4×8 availability in India UNKNOWN | 1–2 kg | MUST BUY | REQUIRES QUOTE | REQUIRES QUOTE |
| 9.2 | Calgon Carbon FORMASORB | HCHO-specific impregnated coconut-shell GAC; 4×8 or 6×12 mesh; lot certificate and SDS required | Kuraray/Calgon Carbon India | Availability in India UNKNOWN | 0.5–1 kg | MUST BUY (for comparison) | REQUIRES QUOTE | REQUIRES QUOTE |

**Procurement note:** Contact Kuraray India (`www.kuraray.com/in-en/`) and Calgon Carbon India for OVC 4×8 and FORMASORB stock, MOQ, SDS, and pricing. If Calgon/Kuraray cannot supply in India at acceptable MOQ, request samples through a global order. Do not substitute with unverified e-commerce activated charcoal.

---

## Category 10 — Safety Equipment

| # | Item | Specification | Example product / vendor | Evidence | Qty | Priority | Est. cost | Status |
|---|---|---|---|---|---|---|---|---|
| 10.1 | Half-face respirator with HCHO cartridge | NIOSH-approved or EN 140 equivalent; A1 or OV cartridge rated for formaldehyde | 3M 6502QL + 3M 6001 (OV/HCHO) or equivalent | CANDIDATE PRODUCT | 2 sets | MUST BUY | ~₹1,000–3,000/set | CANDIDATE PRODUCT |
| 10.2 | Chemical splash goggles | Indirect-vent, EN 166 or ANSI Z87.1 | Standard safety supplier | CANDIDATE PRODUCT | 2 pair | MUST BUY | ~₹200–500/pair | CANDIDATE PRODUCT |
| 10.3 | Chemical-resistant gloves | Nitrile ≥ 0.2 mm; or Viton for extended contact | Standard lab supply | CANDIDATE PRODUCT | 1 box | MUST BUY | ~₹300–600 | CANDIDATE PRODUCT |
| 10.4 | Lab coat (chemical resistant) | Cotton or Nomex; minimum requirement per institutional policy | Standard lab supply | GENERIC REQUIREMENT | 2 | MUST BUY | ~₹500–1,500 | GENERIC REQUIREMENT |
| 10.5 | Spill kit | Absorbent pads; sodium bisulfite solution neutralizes HCHO spills | Standard lab safety kit | GENERIC REQUIREMENT | 1 | MUST BUY | ~₹500–2,000 | GENERIC REQUIREMENT |

---

## Procurement Classification Summary

| Category | Must buy | Can fabricate | Borrow / outsource |
|---|---|---|---|
| Column and pressure hardware | Items 1.4–1.9 | Items 1.1–1.3 (custom fabrication) | 1.7 (reference manometer — may borrow) |
| Flow measurement | 2.1, 2.3; 2.4–2.5 (recommended) | 2.7 (air treatment, can assemble) | 2.6 (air supply — facility) |
| HCHO sensing | 3.1–3.4 | — | — |
| DNPH reference | 4.1–4.4 | — | 4.5 (HPLC service — outsource) |
| T/RH | Included in SFA30 | — | 5.2 (borrow from lab if possible) |
| HCHO generation | 6.1–6.7 | 6.4 (static mixer) | 6.6 (exhaust — facility); full system (institutional lab) |
| Tubing and fittings | 7.1–7.5 | — | — |
| DAQ | 8.1–8.7 | — | 8.6 (monitor/keyboard — borrow) |
| Media | 9.1–9.2 | — | — |
| Safety | 10.1–10.5 | — | — |

---

## Cost Tiers

### Minimum Viable — lowest-cost scientifically defensible setup

Assumes: pressure-drop tests only (no HCHO); no MFC; acrylic column; rotameter flow control; Raspberry Pi DAQ; SFA30 for T/RH only; institutional laboratory for HCHO work when ready.

| Sub-category | Approximate total |
|---|---|
| Acrylic column body + fabrication | REQUIRES QUOTE (est. ~₹3,000–8,000 custom) |
| Retaining screens + fittings | ~₹2,000–5,000 |
| Differential pressure sensor (Sensirion SDP type) | REQUIRES QUOTE (est. ~₹2,000–5,000) |
| Rotameter 0–100 L/min | ~₹1,950 |
| Rotameter 0–300 L/min | REQUIRES QUOTE |
| Raspberry Pi 4B + accessories | ~₹6,000–8,000 |
| SFA30 × 2 (T/RH + orientation check; not HCHO for breakthrough) | ~₹14,200 (₹7,099 × 2) |
| SFA30 breakout boards | ~₹1,500–3,000 |
| PTFE tubing + fittings | ~₹3,000–6,000 |
| Media samples (OVC 4×8) | REQUIRES QUOTE |
| Safety (PPE only) | ~₹3,000–6,000 |
| **Estimated subtotal (India-sourced items only)** | **~₹37,000–53,000 + multiple REQUIRES QUOTE items** |

**HCHO breakthrough testing is NOT included in minimum viable.** It requires institutional laboratory access, MFCs, certified gas cylinder, and DNPH analysis — all in the recommended or reference tier.

### Recommended — best balance of accuracy and cost

Adds: SS316 column body, calibrated MFCs for breakthrough testing, certified HCHO cylinder, DNPH cartridges, external HPLC service, one reference T/RH probe, better DP sensor.

| Additional items vs. minimum viable | Approximate additional cost |
|---|---|
| SS316 column + flanged end caps (fabrication) | REQUIRES QUOTE (est. ~₹8,000–20,000) |
| Differential pressure sensor upgrade (calibrated industrial) | REQUIRES QUOTE |
| MFCs × 2 (zero air + standard gas) | REQUIRES QUOTE (est. US$500–1,500 each; India import) |
| HCHO certified cylinder + regulator | REQUIRES QUOTE (BOC/Linde India) |
| DNPH cartridges × 20 + vials | REQUIRES QUOTE |
| HPLC analysis (external lab, 1 campaign) | REQUIRES QUOTE |
| Area HCHO safety monitor | REQUIRES QUOTE (est. ₹30,000–80,000 for industrial monitor) |
| Humidifier for RH conditioning | REQUIRES QUOTE |
| Reference T/RH probe | REQUIRES QUOTE |
| **Additional estimated total** | **REQUIRES QUOTE — most items need supplier quotes** |

### Reference-grade — higher-confidence laboratory setup

Adds: HPLC instrument access (institutional; not purchased); calibrated optical HCHO analyzer (e.g., Picarro cavity ring-down if available as a loan); three-point DP sensor calibration; NIST-traceable cylinder with independent analytical verification before first test; professional fabricated SS column with integrated pressure taps.

**All items in this tier are REQUIRES QUOTE or BORROW/OUTSOURCE.**

The reference tier is the appropriate level for a peer-reviewed publication; the recommended tier is appropriate for a well-documented student project with institutional laboratory support.

---

## Critical Procurement Blockers

These items must be resolved before any breakthrough testing can begin:

1. **Institutional safety approval** — no purchase of HCHO cylinder until written institutional approval exists
2. **OVC 4×8 and FORMASORB availability and MOQ in India** — contact Kuraray/Calgon Carbon India; if unavailable, all breakthrough planning depends on international procurement
3. **Certified HCHO gas cylinder** (BOC/Linde India) — REQUIRES QUOTE; lead time unknown; import may be required
4. **MFCs** — no current India price found; likely imported; lead time 4–12 weeks
5. **External HPLC laboratory** — identify and confirm an external laboratory before buying DNPH cartridges; laboratory must confirm they can perform ISO 16000-3 or TO-11A carbonyl analysis
6. **Column fabrication** — need a local SS/glass fabricator who can produce a 75 mm ID leak-tight column at an acceptable price

---

## Procurement Priority Order

For a student project starting from scratch, the following sequence is recommended:

1. **Immediately:** contact Kuraray/Calgon Carbon India for OVC 4×8 and FORMASORB samples; contact BOC/Linde India for HCHO cylinder options; identify institutional HPLC laboratory
2. **Next:** buy Raspberry Pi, SFA30 modules, rotameters, PTFE tubing, and basic fittings — these are available now at known prices and needed for rig assembly and clean-air pressure-drop tests
3. **After rig assembly:** buy differential pressure sensor; fabricate or buy column body; perform clean-air pressure-drop tests with OVC media
4. **After institutional safety approval:** order HCHO cylinder, MFCs, DNPH cartridges, scrubber media, and area safety monitor; book external HPLC service
5. **Last:** perform breakthrough tests under institutional supervision

---

*References: all Phase 14, 13 documents and Phase 15 engineering spec; individual item sources cited inline.*

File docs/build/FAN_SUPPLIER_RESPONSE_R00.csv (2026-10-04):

ID | Required_item | Supplier_response | Evidence_reference | Exact_article_revision | Review_status
FS01 | India purchasable fan and controller package | UNKNOWN | UNKNOWN | UNKNOWN | OPEN_NOT_SENT
FS02 | Numeric curves pressure basis density and test installation | UNKNOWN | UNKNOWN | UNKNOWN | OPEN_NOT_SENT
FS03 | 1300 m3h at 250 Pa screening point speed power current sound | UNKNOWN | UNKNOWN | UNKNOWN | OPEN_NOT_SENT
FS04 | 1300 m3h at 420 Pa screening point speed power current sound | UNKNOWN | UNKNOWN | UNKNOWN | OPEN_NOT_SENT
FS05 | 1200 m3h at 375 Pa comparison point | UNKNOWN | UNKNOWN | UNKNOWN | OPEN_NOT_SENT
FS06 | Stable operating range and permissible speed limits | UNKNOWN | UNKNOWN | UNKNOWN | OPEN_NOT_SENT
FS07 | Compact inlet outlet guard installation acceptance or correction | UNKNOWN | UNKNOWN | UNKNOWN | OPEN_NOT_SENT
FS08 | Dimensioned drawing STEP mass mounts orientation service clearance | UNKNOWN | UNKNOWN | UNKNOWN | OPEN_NOT_SENT
FS09 | Actual flow areas spigot tolerance adapters and guards | UNKNOWN | UNKNOWN | UNKNOWN | OPEN_NOT_SENT
FS10 | Matching power control manual supply inrush leakage requirements | UNKNOWN | UNKNOWN | UNKNOWN | OPEN_NOT_SENT
FS11 | Protection reset command loss and available operation feedback | UNKNOWN | UNKNOWN | UNKNOWN | OPEN_NOT_SENT
FS12 | Itemized quote tax freight warranty lead time and replacement service | UNKNOWN | UNKNOWN | UNKNOWN | OPEN_NOT_SENT
FS13 | Selected filter clean curves maintenance limits and revised system duty | UNKNOWN | UNKNOWN | UNKNOWN | OPEN_NOT_SENT
FS14 | Accepted room duty noise and qualified mechanical electrical review | UNKNOWN | UNKNOWN | UNKNOWN | OPEN_NOT_SENT

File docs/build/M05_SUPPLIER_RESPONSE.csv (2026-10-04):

id | owner | required_answer | answer | evidence_reference | reviewer_and_date | review_outcome
H01 | Closure supplier | Exact closure and catch part numbers with revisioned dimensioned drawing or CAD | UNKNOWN | UNKNOWN | UNKNOWN | OPEN
H02 | Closure supplier | Usable closing force versus travel or adjustment and separate working/static load limits | UNKNOWN | UNKNOWN | UNKNOWN | OPEN
H03 | Closure supplier | Panel thickness grip definition cutout mounting and sealed penetration requirements | UNKNOWN | UNKNOWN | UNKNOWN | OPEN
H04 | Closure supplier | Closed and open envelope catch engagement and tools or hand clearance | UNKNOWN | UNKNOWN | UNKNOWN | OPEN
H05 | Gasket supplier | Exact door gasket profile material free thickness and dimensional tolerances | UNKNOWN | UNKNOWN | UNKNOWN | OPEN
H06 | Gasket supplier | Full force versus compression data allowed compression range and test conditions | UNKNOWN | UNKNOWN | UNKNOWN | OPEN
H07 | Gasket supplier | Corner and joint method adhesive compatibility aging/environment limits and replacement instructions | UNKNOWN | UNKNOWN | UNKNOWN | OPEN
H08 | Filter supplier | Exact HEPA seating gasket clamp requirements mass and permitted handling/orientation | UNKNOWN | UNKNOWN | UNKNOWN | OPEN
H09 | Mechanical reviewer | Actual pressure/load cases panel and flange deflection joints mounts and compression-stop review | UNKNOWN | UNKNOWN | UNKNOWN | OPEN
H10 | Mechanical reviewer | Supported cover removal drop retention service sequence and complete tolerance stack | UNKNOWN | UNKNOWN | UNKNOWN | OPEN
H11 | Mechanical and electrical reviewers | Removable panel bonding needs isolation and coordinated safe access arrangement | UNKNOWN | UNKNOWN | UNKNOWN | OPEN
H12 | Reviewer and test provider | Installed sealing test method acceptance criteria and recorded review of revised assembly drawings | UNKNOWN | UNKNOWN | UNKNOWN | OPEN

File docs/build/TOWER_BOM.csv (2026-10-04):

ID | Item | Quantity | Selection status | Required before ordering | Cost status
T01 | Fan assembly | 1 | Historical KVO 250 candidate only | Exact SKU current loaded-duty curve envelope wiring warranty noise | RFQ REQUIRED
T02 | Coarse prefilter | 1 plus spare | 592x592x48 candidate | Supplier curve classification washable instructions tolerances | RFQ REQUIRED
T03 | HEPA element | 1 | 593x593x292 H13 candidate | Unit certificate dimensions mass gasket and terminal pressure | RFQ REQUIRED
T04 | HEPA cassette and clamps | 1 | Custom metal assembly | Seal section compression tolerance leak-test plan | RFQ REQUIRED
T05 | Prefilter cassette | 1 | Custom assembly | Fit and replacement access | RFQ REQUIRED
T06 | Frame base and enclosure | 1 | Local fabricated metal | Released drawings stability material and coating | RFQ REQUIRED
T07 | Fan support and isolators | 1 set | Custom support with rated mounts | Fan mass vibration and load review | RFQ REQUIRED
T08 | Transitions guards and duct fittings | 1 set | Standard where practical | Dimensions guard safety pressure-loss budget | RFQ REQUIRED
T09 | Gaskets sealant and retained latches | 1 set | Compatible low-emission materials | OEM gasket requirements durability and seal inspection | RFQ REQUIRED
T10 | Electrical compartment and glands | 1 set | Certified/rated components preferred | Environment ingress heat and segregation review | RFQ REQUIRED
T11 | Protection isolation and motor control | 1 set | Electrical engineer selection | OEM thermal circuit inrush and supply coordination | RFQ REQUIRED
T12 | Cables terminals earth bonding | 1 set | Electrical engineer selection | Cable route ratings and approved schedule | RFQ REQUIRED
T13 | Isolated low-voltage supply | 1 | Off-the-shelf | Sensor/controller load and protection | RFQ REQUIRED
T14 | Logger controller | 1 acquisition arrangement | Existing laptop and exports first; bridge/controller unselected | Actual instrument interfaces duplicate addresses safe low-voltage supply and no safety dependency | USE EXISTING OR RFQ
T15 | Filter pressure measurement | 2 simultaneous channels recommended | Buy calibrated instrument or rent; SDP8xx candidate only | Actual loaded/fault range accuracy tubing address routing and reference check | PURCHASE OR RENT RFQ
T16 | Particle sensors | 2 matched room monitors recommended | Buy supported complete instruments/kits; SEK-SPS30 candidate only | Exact kit contents exports co-location usable floor reference comparison humidity and protocol | RFQ REQUIRED
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

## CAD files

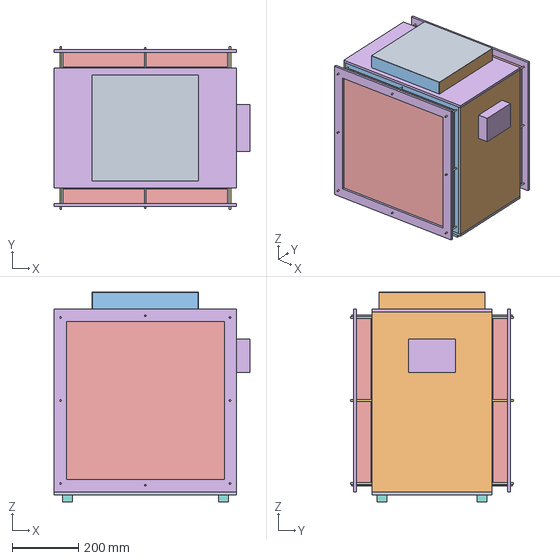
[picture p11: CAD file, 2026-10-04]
reports/prototype_d01/D01_ASSEMBLY.step
590.0 x 490.0 x 631.0 mm

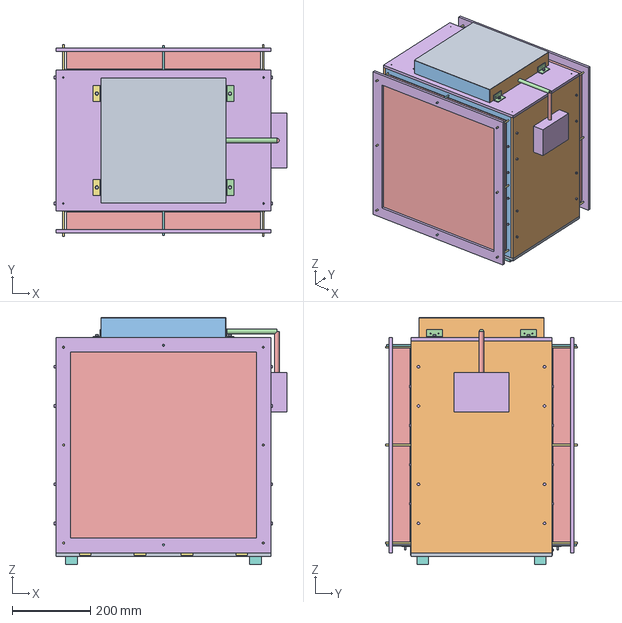
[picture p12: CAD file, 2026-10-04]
reports/prototype_d01/r01/D01_R01_ASSEMBLY.step
594.0 x 490.0 x 631.0 mm

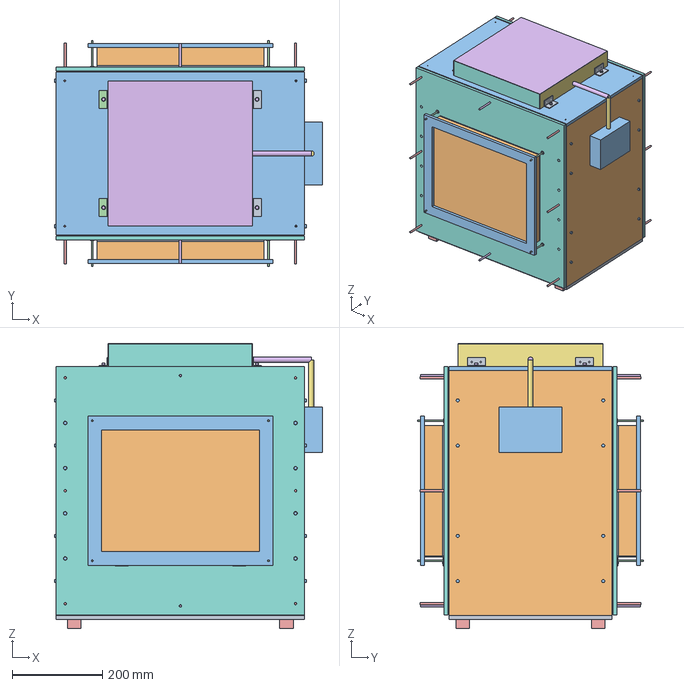
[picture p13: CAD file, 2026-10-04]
reports/prototype_d01/r02_adapter/D01_R02_ASSEMBLY.step
594.0 x 500.0 x 631.0 mm

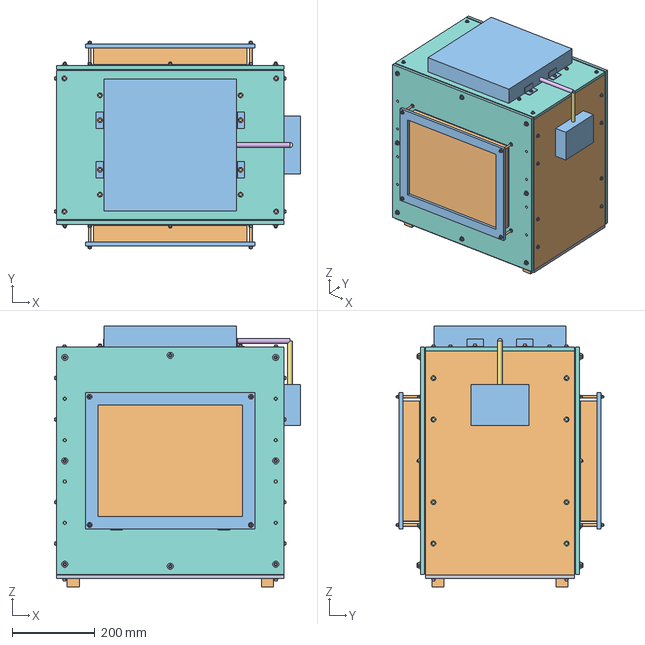
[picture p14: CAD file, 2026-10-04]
reports/shareable_20261005/technical/engineering/reports/prototype_d01/mechanical_package/D01_R03M_ASSEMBLY.step
595.0 x 504.0 x 631.0 mm

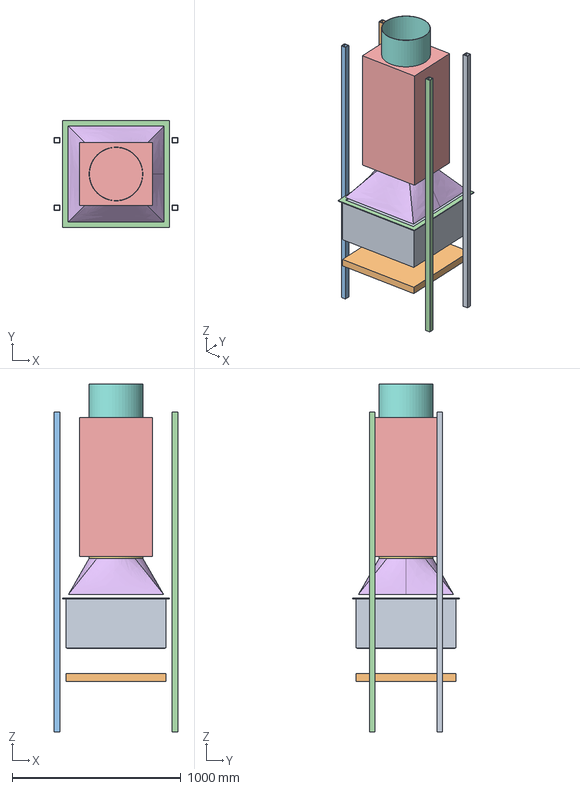
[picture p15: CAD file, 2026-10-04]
cad/packaging/AQI_M05_HEPA_Service_Hatch_STUDY.FCStd
735.0 x 633.0 x 2065.0 mm
HEPAEnvelope
PrefilterEnvelope
HEPAGasketEnvelope
HEPARetainerEnvelope
FanAllowance
Transition
InletNeck
StraightOutlet
Post1
Post2
Post3
Post4

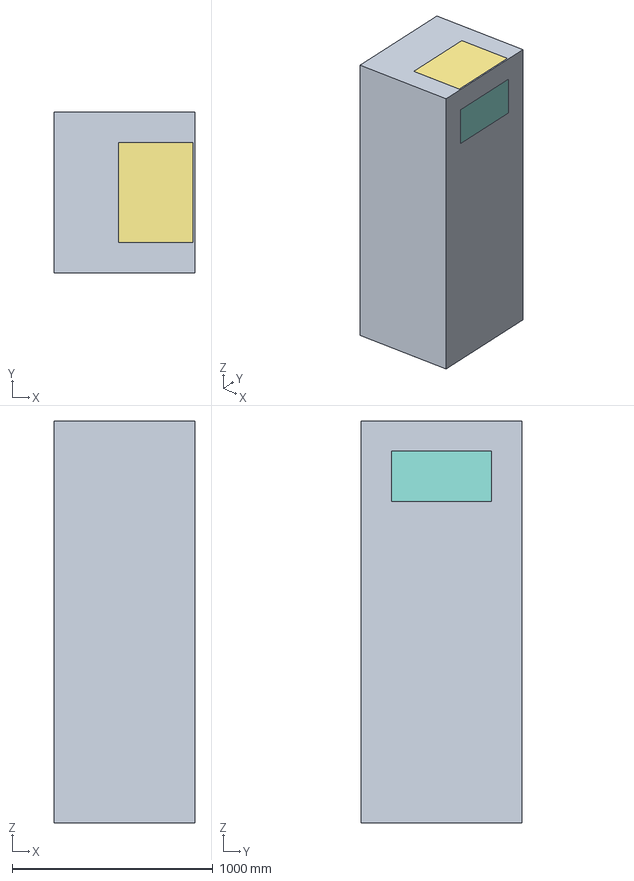
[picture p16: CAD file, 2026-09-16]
cad/parametric/AQI_Tower_ConceptA_GEO_A.FCStd
700.0 x 800.0 x 2000.0 mm
TowerEnvelope — REFERENCE ONLY
Inlet [AIR_INLET]
DirtyAirPlenum [DIRTY_PLENUM]
InterstageGap_01
InterstageGap_02
CleanAirPlenum [CLEAN_PLENUM]
CleanAirRiser [CLEAN_RISER]
Outlet [AIR_OUTLET]
TurnStep_01 [TURN_STEP_01]
TurnStep_02 [TURN_STEP_02]
TreatmentStage_01 [STAGE_01 — EMPTY]
TreatmentStage_02 [STAGE_02 — EMPTY]
TreatmentStage_03 [STAGE_03 — EMPTY]

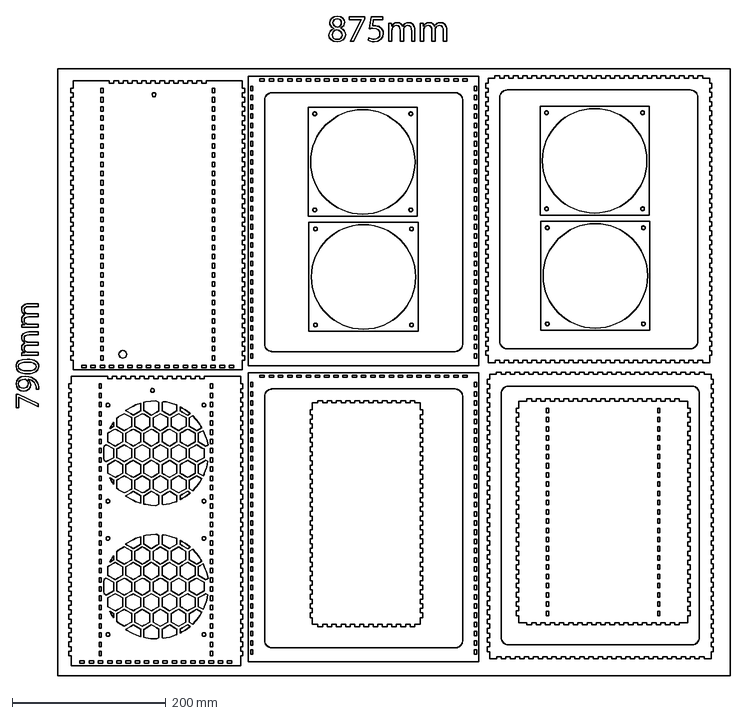
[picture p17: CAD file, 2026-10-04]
data/prototype_d01/sources/Brisa_CC0_reference.dxf
929.1 x 858.0 mm

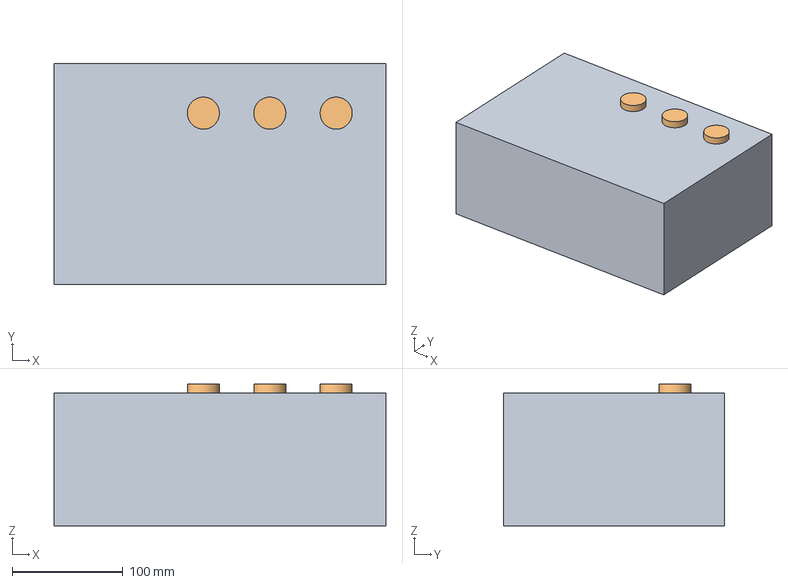
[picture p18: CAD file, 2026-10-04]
reports/prototype_d01/electrical_package/control_module/D01_E05_CURRENT_CONTROL_LAYOUT.step
300.0 x 200.0 x 128.1 mm

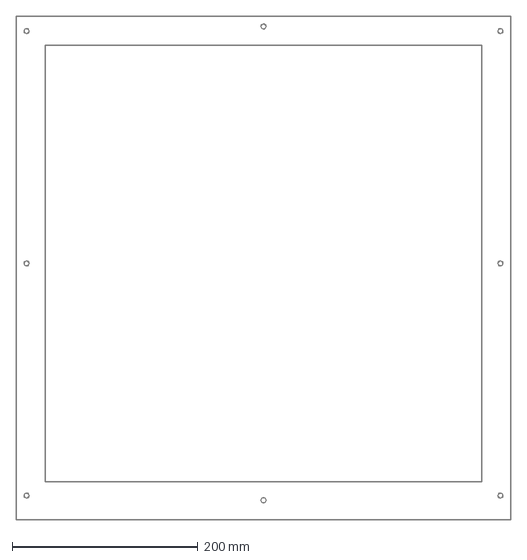
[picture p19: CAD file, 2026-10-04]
reports/prototype_d01/panel_dxf_REVIEW_ONLY/M03_SEAT.dxf
532.0 x 542.0 mm

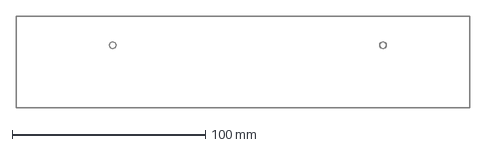
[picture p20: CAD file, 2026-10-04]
reports/prototype_d01/r01/panel_dxf_REVIEW_ONLY/M05_FRONT_RIGHT.dxf
235.0 x 47.5 mm

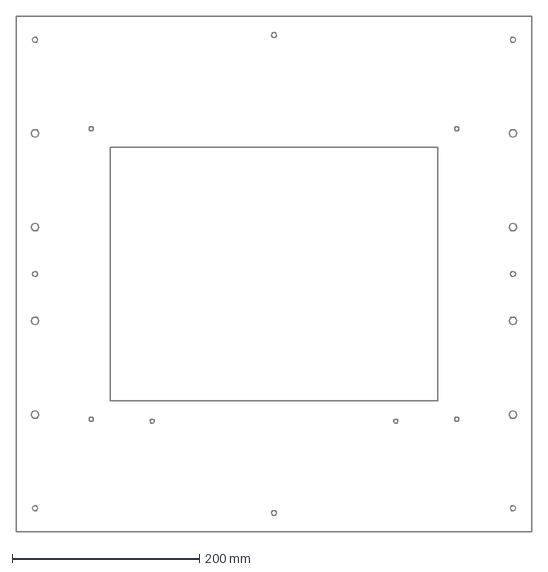
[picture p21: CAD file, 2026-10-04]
reports/prototype_d01/r02_adapter/panel_dxf_REVIEW_ONLY/A01_REDUCER.dxf
550.0 x 550.0 mm

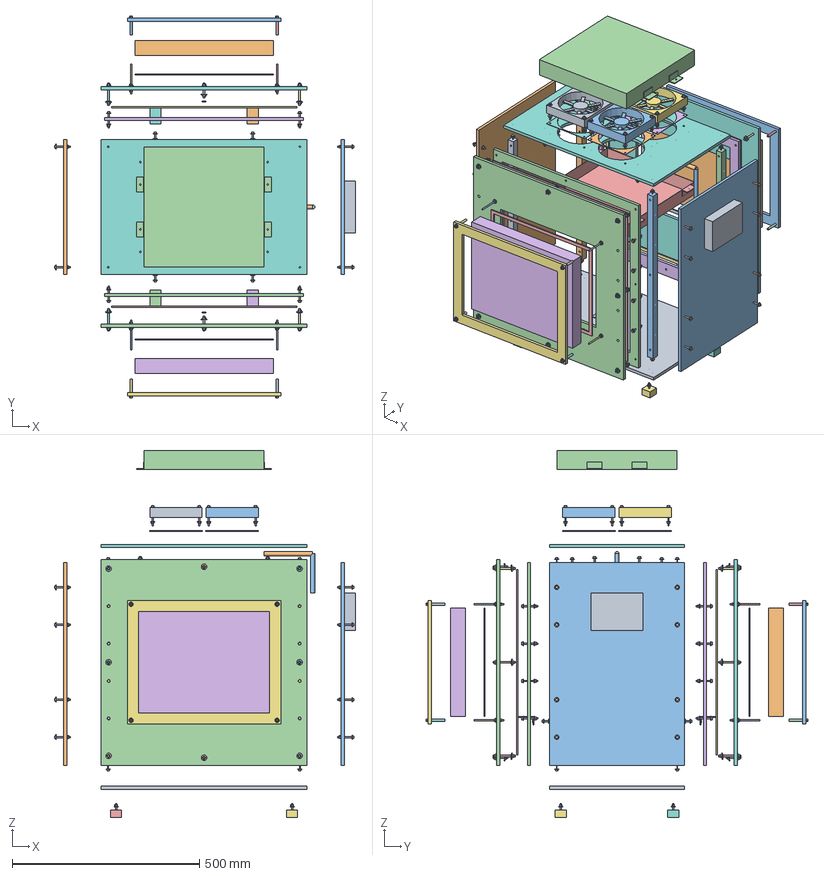
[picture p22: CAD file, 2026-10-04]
reports/shareable_20261005/technical/engineering/reports/prototype_d01/mechanical_package/D01_R03M_EXPLODED.FCStd
805.0 x 1020.0 x 981.0 mm
M01_Base
M02_Left
M02_Right
M03_Seat_Front
S01_Filter_seal_Front
M03_Seat_Rear
S01_Filter_seal_Rear
S02_Fan_seal_1
F02_P14_Max_1
S02_Fan_seal_2
F02_P14_Max_2
S02_Fan_seal_3
F02_P14_Max_3
S02_Fan_seal_4
F02_P14_Max_4
M06_Fan_plate
M07_Cleat_9_9
M07_Cleat_9_331
M07_Cleat_521_9
M07_Cleat_521_331
M08_Foot_25_15
M08_Foot_25_315
M08_Foot_495_15
M08_Foot_495_315
E01_Control_box_RESERVATION
H10_False_19_19
H10_False_19_341
H10_False_531_19
H10_False_531_341
H10_True_19_19
H10_True_19_341
H10_True_531_19
H10_True_531_341
E02_Cable_corridor_0
E02_Cable_corridor_1
A01_Reducer_Front
A02_Filter_gasket_Front
A03_STARKVIND_envelope_Front
A04_Retainer_Front
A06_Feedthrough_seal_0_Front
A06_Feedthrough_seal_1_Front
A06_Feedthrough_seal_2_Front
A06_Feedthrough_seal_3_Front
A07_Ledge_130_Front
A09_Ledge_seal_130_Front
A07_Ledge_390_Front
A09_Ledge_seal_390_Front
A01_Reducer_Rear
A02_Filter_gasket_Rear
A03_STARKVIND_envelope_Rear
A04_Retainer_Rear
A06_Feedthrough_seal_0_Rear
A06_Feedthrough_seal_1_Rear
A06_Feedthrough_seal_2_Rear
A06_Feedthrough_seal_3_Rear
A07_Ledge_130_Rear
A09_Ledge_seal_130_Rear
A07_Ledge_390_Rear
A09_Ledge_seal_390_Rear
A05_Stud_0_Front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

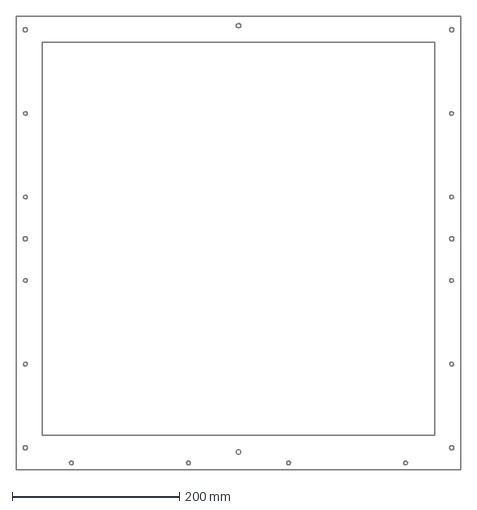
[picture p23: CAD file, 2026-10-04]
reports/shareable_20261005/technical/engineering/reports/prototype_d01/mechanical_package/panel_DXF_REVIEW_ONLY/M03_Seat_Front.dxf
532.0 x 542.0 mm

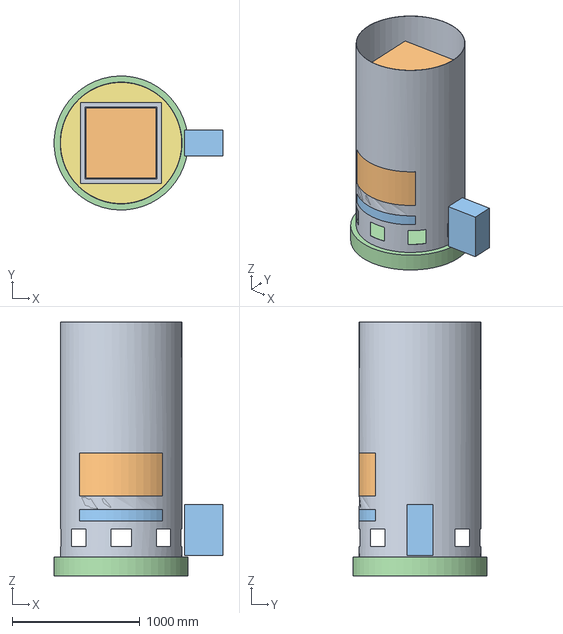
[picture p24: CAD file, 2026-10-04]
cad/packaging/AQI_Cylindrical_Packaging_R01_NOT_FOR_FABRICATION.step
1321.0 x 1049.5 x 1990.0 mm

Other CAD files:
reports/prototype_d01/r02_adapter/hardware_detail/D01_R02H_ASSEMBLY.step
reports/prototype_d01/r02_guards/D01_R02G_ASSEMBLY.step
reports/shareable_20261005/technical/engineering/reports/prototype_d01/electrical_package/control_module/D01_E05_CURRENT_CONTROL_LAYOUT.step
reports/shareable_20261005/technical/engineering/reports/prototype_d01/mechanical_package/harness_detail/D01_R03M_HARNESS_REVIEW.FCStd
cad/packaging/AQI_Cylindrical_Packaging_R00.FCStd
cad/packaging/AQI_Cylindrical_Packaging_R00_NOT_FOR_FABRICATION.step
cad/packaging/AQI_Cylindrical_Packaging_R01.FCStd
cad/packaging/AQI_Cylindrical_Packaging_R02.FCStd
cad/packaging/AQI_Cylindrical_Packaging_R02_NOT_FOR_FABRICATION.step
cad/packaging/AQI_M02_Frame_Routing_NOT_FOR_FABRICATION.step
cad/packaging/AQI_M02_Frame_Routing_STUDY.FCStd
cad/packaging/AQI_M02_M03_Integrated_Fit_STUDY.FCStd
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

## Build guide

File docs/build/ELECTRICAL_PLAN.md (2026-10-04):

# Electrical and monitoring plan

**Current D01 control fit, 5 October:** [E05 same-module CAD/drawing and checks](../../reports/prototype_d01/electrical_package/control_module/README.md) closes assumed button-tail/service-space clashes without reducing reservations. [Current build decision](../../reports/prototype_d01/electrical_package/control_module/D01_CURRENT_BUILD_DECISION.pdf) consolidates the open release gates. Actual contact minimum ratings, button/connector stack, supports, gauges/terminals, hazard allocation and rated protection remain unverified. Default Opta relays disabled; no wiring/energization approval. Live speed adjustment not designed; disconnected-source preset is only a review proposal.

**Latest D01 supplement, 5 October:** [E01 power and wiring review](../../reports/prototype_d01/electrical_package/AQI_D01_POWER_AND_WIRING_SUPPLEMENT.pdf) and [coordination arithmetic](../../reports/prototype_d01/electrical_package/POWER_COORDINATION.json). Four-page connector-level drawing, official fan pin functions,20 assumed load/36 wire-drop examples and10 tests. Rated protection/manual restart, conductor/fuse selection and enclosure remain OPEN. This does not supersede the existing control-sequence requirements or release hardware.

**Current prototype reference, 5 October 2026:** [IH02 engineering handoff](../../reports/prototype_d01/internal_handoff_20261005/START_HERE.md) controls the D01 review: four12V P14 Max fans and proposed OEM Noctua power/control chain. The historical230V large-tower plan below is not a D01 wiring instruction. Rated protection, enclosure/harness and commissioning remain unfinished; use the current electrical appendix and release register for internal review.

PRELIMINARY FUNCTIONAL PLAN — NOT A WIRING DRAWING. 2 October 2026.

Delivery basis updated 3 October 2026: college/NGO funding only, no college lab assumed. Assistant prepares OEM-based drawings/calculations/software; ENTC review is optional/unconfirmed. Hire qualified review/assembly/commissioning where needed. See [no-lab route](NO_LAB_BUILD_ROUTE.md) and [review handout](OPTIONAL_ENTC_REVIEW.md).

The historical fan data says 230 V AC, 50 Hz, 301 W, 1.33 A, thermal contacts and a 7 microfarad capacitor. Confirm exact model and OEM diagram: AC and EC variants cannot be interchanged using old wiring. Never infer fuse/cable sizes from nominal current alone.

```mermaid
flowchart LR
    A[Approved mains supply] --> B[Protection and lockable isolation]
    B --> C[Motor control with OEM thermal protection]
    C --> D[OEM fan and approved speed controller if needed]
    B --> E[Certified isolated low-voltage power supply]
    E --> F[Controller and sensors]
    G[Protective earth] --> H[Bond fan frame and exposed metal enclosure]
    I[Local stop and service interlock] --> C
```

This diagram explains functions only. Protective devices' coordination, emergency-stop need/category, neutral handling, interlock architecture and earthing must be selected by the electrical reviewer for the actual installation. Never switch or fuse protective earth.

## Minimum functions

Outdoor thermal/ingress and tamper-access requirements are now recorded in [India deployment basis](INDIA_DEPLOYMENT_BASIS.md). D01's 40 C fan ceiling does not qualify it for hot outdoor sites. No existing enclosure or protective chain is released for rain, public access or automatic temperature shutdown.

- Qualified electrical review is required for upstream residual-current and overcurrent protection, isolator, motor-rated switching, surge measures if needed, wiring sizes, glands and terminals. The assistant prepares selection calculations from verified inputs for review. Coordinate with the actual installation supply and applicable Indian requirements; do not assume a campus site.
- OEM thermal protection remains effective. Do not bypass it to obtain higher flow. Do not connect the mains fan directly to Arduino/ESP32 GPIO or a hobby relay board; no improvised PWM mains control.
- Exposed conductive parts are bonded appropriately. Mains and low-voltage wiring are segregated, strain-relieved and guarded. Service isolation is lockable; opening a panel must not expose accessible live conductors.
- Proposed first prototype behaviour: local on/off, manual restart after power loss or safety trip, and no unattended remote start. Engineer reviews service-door interlocking and fan run-down hazards.
- Controller failure must not defeat safety functions. Wireless networking is optional and not a prerequisite for cleaning.

## Measurements

Log time, fan setting, pressure across each filter, total airflow measured by an appropriate duct traverse/flow hood method, electrical power, temperature/humidity and paired particle readings. Particle sensors are useful for trends, not certified filter leak tests. Buy appropriate monitoring instruments; hire an equipped test service or rent calibrated specialist instruments with competent operators. No college borrowing assumed.

Start with an off-the-shelf isolated logger/controller rather than a custom PCB. Select sensors only after ranges, sampling plan, accuracy and calibration access are agreed. Do not reuse the low-flow carbon laboratory instrument specification as a tower airflow specification.

## Required electrical release pack

New R00 preparation: [core operating/fault sequence and commissioning witness cases](CORE_CONTROL_SEQUENCE.md), [functional visual](CORE_ELECTRICAL_FUNCTIONS.svg) and [unreleased interface register](CORE_ELECTRICAL_INTERFACES.csv). Defines deliberate restart, access/run-down review and independent monitoring. No rated circuit or physical test has been completed.

E01 single-line diagram; E02 complete OEM-based power/control schematic; E03 terminal and cable schedule; E04 enclosure layout and earthing drawing; E05 component ratings and coordination calculation; E06 commissioning checklist. These are not yet complete: exact fan/controller, supply fault conditions, cable length, enclosure environment and protection choices remain UNKNOWN.

Before energizing, a qualified person checks protective-earth continuity, insulation and relevant leakage/protection tests, polarity/termination, thermal function, isolator/interlocks, fan rotation, guards and abnormal operation under the applicable procedures. This planning note does not specify test voltages or certify compliance.

Historical fan-only energy at 301 W for eight hours is 2.408 kWh; measured consumption including controls will govern solar planning. Do not design panels/battery/inverter from this single nominal value.

Reference: IEC 60335-2-65:2023 addresses household/similar air-cleaning appliance safety, used with Part 1. Its public scope is a review starting point, not a claim that our outdoor machine complies or that this is its only applicable standard: https://webstore.iec.ch/en/publication/70378 . Have the qualified reviewer determine classification and Indian applicability.

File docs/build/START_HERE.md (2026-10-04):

# From digital study to a real tower

**Current consolidated delivery — 5 October:** [56-page technical handoff](../../reports/shareable_20261005/technical/AQI_TOWER_TECHNICAL_HANDOFF.pdf) and [two-audience bundles](../../reports/shareable_20261005/README.md). Read current decision/E05/E02 pages1–6 first; earlier50-page reference follows unchanged. [E05 control fit](../../reports/prototype_d01/electrical_package/control_module/README.md) closes E04 assumed service-space conflicts by rearrangement without reducing reservations. [Current release register](../../reports/prototype_d01/electrical_package/control_module/CURRENT_RELEASE_GATES.csv) keeps actual mechanical/electrical/physical gates open. This supersedes older fit/navigation status below, not historical evidence. Consolidated review handoff only; NOT construction or energization release.

**Current navigation — 5 October 2026:** use [IH02 internal handoff](../../reports/prototype_d01/internal_handoff_20261005/START_HERE.md). It consolidates R03M geometry, electrical reference, current pressure and measurement tools, drawings and engineer/stakeholder PDFs. Earlier full-size tower plans and dated handoffs below are historical; their mains fan, filter and pressure assumptions must not be mixed with the current D01 prototype. OEM enquiries are sent, technical replies pending. The handoff is ready for review; construction release remains open for guard/structure/seal, rated electrical and exact-component evidence.

**Harness evidence boundary:** current OEM fan drawing and extension datasheet checked; exact cable/connector clamping dimensions still unavailable in reviewed material. See [harness findings](../../reports/prototype_d01/mechanical_package/harness_detail/README.md). Authorized technical enquiries have now been submitted to ARCTIC (success confirmed) and Noctua (ticket220175); see [record](OEM_CABLE_ENQUIRIES.md). No replies, purchases or release. Do not substitute guessed guard cutouts for missing evidence.

**Harness interface update:** [routing study](../../reports/prototype_d01/mechanical_package/harness_detail/README.md). Four collision-checked internal routing reservations added to a preserved-geometry integrated review CAD. Assumed3 mm envelopes/emergence points only; actual protected entry/strain relief not complete and no guard cut. Candidate300 mm extensions for two longer paths; OEM connector/lead geometry and insert compatibility still needed.

**Latest guard/access decision:** [geometry-based hazard mapping](../../reports/prototype_d01/mechanical_package/GUARD_ACCESS_DECISION.md). Native read-only audit confirms guard/fan-body separations, but no reach compliance. Corrects earlier cable-crossing wording: external reservation is tangent; internal harness/feed-through not modeled. Proposes independent fixed guards and isolated servicing for qualified assessment, not removal of restart requirements. Next close actual cable entry, guard reach/strength and isolation before selecting interlocks.

**Latest electrical decision:** [protective candidate screen](../../reports/prototype_d01/electrical_package/PROTECTIVE_SELECTION_DECISION.md). Three exact OEM candidates assessed; eight checks pass. No complete protective assembly selected. Clarifies why supply/headroom/enclosure/monitoring limitations prevent a drop-in and why actual access hazards must determine required protection. Does not waive existing requirements. Supplement is separate from the earlier E00 ZIP/PDF.

**Package 3 validation V00:** [current test and calculation package](../../reports/prototype_d01/validation_package/README.md). R03M guard pattern area is 0.0354623 m2 each; conditional filter allowance now14.32 Pa at assumed300 m3/h total, K1 reducer. Three blank CSV measurement sheets, strict airflow analyzer,15 synthetic/arithmetic checks and five-page procedure. No actual flow, CADR, physical test or safety approval. Three consolidated review packages delivered; actual protective/mechanical interface closure and qualified commissioning still precede testing.

**Package 2 electrical review E00:** [consolidated electrical package](../../reports/prototype_d01/electrical_package/README.md), 4 October. OEM reference power chain, seven-page schematic/review, power budget, interface/BOM CSVs and executable restart acceptance tests. Protective module remains UNSELECTED. Hub self-reset and single upstream RPM channel cannot fulfill independent protective restart monitoring. No terminal/fuse/cable ratings invented. Mechanical CAD unchanged; no energization release. See the package's three explicit electrical closure gates.

**Latest assembly / package1:** [R03M mechanical package](../../reports/prototype_d01/mechanical_package/README.md). One batch covers fastener stacks, joined guards, foot retention, seal stops, CAD/exploded view, drawings and assembly sequence.493 objects and119,805 checked pairs clear. Do not mix old rod lengths/base/guard blank patterns with this revision. Mechanical materials/strength/seal/access holds remain; package2 controls/enclosure interface unresolved. Review only.

**START WITH THE CONSOLIDATED HANDOFF:** [current D01 review package](../../reports/prototype_d01/current_handoff/README.md).15-page PDF and bundled current assembly,10 CAD-extracted panel DXFs, inventory and explicit missing items.29,116 whole-assembly checked pairs clear;774 excluded. Current conditional pressure allowance14.61Pa/filter at300m3/h total under stated assumptions, NOT actual flow. Mechanical/electrical/performance gates remain OPEN. This replaces navigation between delta-only deliveries; historical material follows.

**Current assembly:** [R02G independent guard mountings](../../reports/prototype_d01/r02_guards/README.md). Separates four shared bolts into four per guard.245 valid objects;8,641 changed-part pair checks and16 assumed tool checks clear. Revised plate/skirt drilling and hardware drawing supplied. Guard seams/rivets, strength, reach protection, electrical isolation/restart and filter evidence remain unresolved. Review only.

**Current hardware detail:** [R02H fastening/service revision](../../reports/prototype_d01/r02_adapter/hardware_detail/README.md).229 valid objects;13,644 changed-part pair checks and two200 mm filter sweeps clear. Adapter nuts/washers/heads now modeled. Tool access, inherited M5/guards, seal/strength and electrical gates remain open. No construction release.

**Latest integrated CAD:** [R02 removable filter adapter](../../reports/prototype_d01/r02_adapter/README.md).169 objects,5,310 new-part pair checks clear, native/STEP checks pass. Review-only cassette on the existing cabinet; new sealing/support features and dimensioned drawings provided. DO NOT use R01 airflow predictions for this different filter. No construction/energization release.

**Current user direction: internet-only sourcing preparation; no supplier-chasing task for the user.** [Online alternatives and actual interface comparison](../../reports/prototype_d01/component_validation/D01_ONLINE_FILTER_OPTIONS.pdf) now supersedes the inquiry-sending workflow below. IKEA/Smart Air options need sealed adapters and pressure validation; Filtrete import offers are costly and inconsistent. Inquiry gasket490/470mm was erroneous; saved CAD uses495.3/475.3mm. No purchase/fabrication release.

**Filter decision needs external data:** [prepared technical inquiry](../../reports/prototype_d01/component_validation/FILTER_INQUIRY_UNSENT.md), not sent. Exact dimensions and per-filter low-flow resistance are requested; returned-data checker has ten passing synthetic tests. No obtainable drop-in filter is approved yet. Sending or ordering requires explicit user authorization.

**Deployment boundary:** [India heat, robustness and size review](INDIA_DEPLOYMENT_BASIS.md). D01 is not suitable for unattended public/outdoor use. Keep supervised indoor prototype closure on the critical path; outdoor heat/weather/tamper protection require a separately qualified assembly and actual host site. Five added calculation checks completed, not safety certification.

**Latest component evidence:** [D01 fan-data comparison and filter allowance](../../reports/prototype_d01/component_validation/README.md). OEM numeric curve archived, source discrepancies retained; nine checks pass. R01 CAD unchanged. Approximately14.5Pa filter allowance at300m3/h total is a provisional selection screen, not tested performance. Exact obtainable filter and safety details still block construction release.

**D01 continuation:** [R01 construction detail package](../../reports/prototype_d01/r01/README.md) now updates the same assembly with guard brackets, cabinet joints, shelf supports and cable routing. R01 drilling files and revised pressure assumptions supersede corresponding R00 details for review, not for fabrication release.

**Latest 3 October recommendation:** [D01 integrated indoor demonstrator](../../reports/prototype_d01/README.md) now supplies one CAD assembly, drawings, BOM and calculation package. It proposes a smaller 12 V/MERV13 first build to unblock physical learning; it does not validate or release the full-size HEPA plan below. Physical prototypes remain0. Read its explicit component, mechanical and restart-control gaps before treating any drawing as a construction instruction.

Updated: 3 October 2026. Status: preliminary planning, NOT released for fabrication.

## The decision

Build one full-size particulate-filtering prototype first, test it indoors, then investigate outdoor operation. The final goal remains an outdoor tower network. An indoor test is a controlled stepping stone, not proof of outdoor coverage.

User clarification: previous small-device work was digital, not a physical test. No physical tower measurements are available in the reviewed records. College/NGO support is funding only: no college lab assumed. Pune, Hyderabad or Mumbai are possible locations; actual premises/room and outdoor site remain UNKNOWN. Budget should be reasonable; no fixed ceiling or deadline was supplied. An ENTC reviewer is optional/unconfirmed; the assistant still prepares the design and software.

The first build path is **guarded intake -> removable coarse prefilter -> sealed HEPA cassette -> clean-air plenum -> fan -> guarded outlet**. Reserve space for a removable gas-filter module, but do not fit an uncharacterized carbon bed or claim gas cleaning in the first demonstration. This is a RECOMMENDATION to speed particulate validation; the research concept with carbon remains in the historical records. No water stage, ionizer or ozone generator. Grid power first; solar after measuring consumption.

## What already exists and what does not

| Item | Evidence/status | What must happen next |
|---|---|---|
| GEO_C airflow layout | DETECTED: digital geometry optimization | Convert into a physical assembly; GEO_C is not a construction drawing |
| Sealed HEPA airflow | DETECTED: about 1,332 m3/h in `results/FILTER_H13/bypass_analysis_sealed.json` | Partial/nonconverged CFD; verify actual airflow and bypass |
| Physical filter size | DETECTED: candidate HEPA 593 x 593 x 292 mm | Old `docs/CAD_V00.md` has 30 mm stage placeholders; rebuild packaging |
| Seal | DETECTED: CFD boundary closes a bypass path | Draw gasket, clamping frame and door; boundary condition does not prove leak-tightness |
| Fan | DETECTED: historical KVO 250/KVO 250 L data, 250 mm port, 301 W, 20 kg | Confirm exact SKU, current curve, envelope, wiring and availability with OEM |
| Physical test | NOT DONE in reviewed records; confirmed digital-only by user | Obtain instruments and conduct controlled tests |
| Mechanical structure | Missing fabrication drawings, mass/stability calculations | Mentor/fabricator review before release |
| Electrical system | Missing rated wiring, protection and terminal drawings | Electrical engineer review and qualified assembly |
| Procurement | Historical lab BOM is not a tower BOM | Use the new preliminary tower parts list |
| Outdoor bubble | UNKNOWN | Measure breathing-height effects under wind; no guaranteed radius |

Also: `cad/parametric/v00.json` describes a different small envelope from CAD_V00. Do not treat all historical models as one physical machine. Phase 19 and pressure-budget records use differing prefilter loading thresholds; set the maintenance limit from supplier data and measured operating flow, not an inherited 80/100 Pa number.

## Calculations that change the build decision

Run `python scripts/analysis/build_screening.py`. Its generated output is `results/build_screening.json`. These are screening calculations, not a fresh CFD run or measured performance.

- A 250 mm connection carrying 1,300 m3/h has about 7.36 m/s velocity and 32.5 Pa dynamic pressure (density assumed 1.2 kg/m3). Bends, guards and transitions can matter: an assumed loss coefficient of 1 adds about 32.5 Pa. Do not trust the historical 3.8 Pa residual as the whole new tower's loss.
- At 1,300 m3/h, the historical fan curve is already nearly consumed by the modeled clean HEPA/prefilter combination. The earlier claim of 57–67 Pa spare carbon margin must not be used at that same flow. Available head must be compared with ALL losses at the SAME target flow.
- An illustrative carbon contact time of 0.1 seconds would require about 36 litres of bed volume at 1,300 m3/h. This says nothing about gas removal or bed pressure drop; those require material-specific data.
- If whole-device efficiency were 90%, an illustrative 1,300 m3/h flow gives 1,170 m3/h effective clean-air flow. At an assumed 5 air changes/hour and 3 m ceiling, that corresponds to 78 m2 in an ideally mixed enclosed room. Neither the efficiency nor that area is a tested rating.
- Wind at 1 m/s through an illustrative 10 m wide x 2 m high outdoor section carries 72,000 m3/h. Comparing this with 1,300 m3/h shows why an indoor result cannot establish a large outdoor bubble. This is a scale comparison, NOT a predicted cleaning percentage.

The current fan is a benchmark candidate, not a commitment for the larger final tower. Request competing fan curves at a defined loaded-system duty point. More free-air flow alone is not enough.

## Read the build package

Fan decision input: [copyable selection brief and three-flow duty comparison](FAN_SELECTION_BRIEF_R00.md), with [response sheet](FAN_SUPPLIER_RESPONSE_R00.csv). Screening only; actual room/filter/OEM installation inputs remain required. Not sent or order-ready.

Electrical development: [core operating sequence](CORE_CONTROL_SEQUENCE.md), [functional schematic](CORE_ELECTRICAL_FUNCTIONS.svg) and [interface register](CORE_ELECTRICAL_INTERFACES.csv). Preliminary requirements and fifteen unexecuted witness cases; exact fan, supply and rated wiring still open.

Current execution basis: [build without a college lab](NO_LAB_BUILD_ROUTE.md), [funded work packages](FUNDED_WORK_PACKAGES.csv) and [optional ENTC review handout](OPTIONAL_ENTC_REVIEW.md). Buy/rent equipment and hire scoped physical services; no dependency on a college lab or the optional friend. Core-first/cladding-later is a recommendation, not an architecture release.

Equipment preparation: [buy/rent indoor instrument kit](INDOOR_INSTRUMENT_KIT.md) and [revised request sheet](INDOOR_INSTRUMENT_REQUEST_NO_LAB.csv). Official sensor/flow-instrument references checked; addresses, measurement ranges and conceptual pressure-tap mapping documented. Actual devices/calibration/interfaces still UNKNOWN; no order or wiring release. Previous college-based CSV is superseded.

Analysis preparation: [single-pair indoor particle-decay tool](INDOOR_DECAY_ANALYSIS.md). Works with recorded CSV and explicit windows/assumptions; synthetic tests only. No confidence interval or physical performance result; requires reviewer assessment and repeated trials before interpretation.

Monitoring preparation: [offline measurement recorder and first-trial data format](MEASUREMENT_RECORDING.md), metadata template and eight synthetic tests. It does not connect sensors or control the fan; no data collected. This independent software task proceeds while closure/component data and engineering review remain outstanding.

Action package: [HEPA closure review request and acceptance sequence](M05_CLOSURE_REVIEW_PACKAGE.md), with [supplier/reviewer response sheet](M05_SUPPLIER_RESPONSE.csv). Prepared, not sent. Obtain component-specific closing-force/gasket data and mechanical review before a new closure CAD branch; keep other build gates separate.

Newest evidence: [OEM hatch hardware and gasket check](M05_HARDWARE_GASKET_REVIEW.md). Real cutouts exceed the assumed rim; gasket compression force cannot be inferred from door pressure. No replacement latch or seal selected. Review closure/catch and gasket data before another fabrication-detail branch.

Newest service detail: [M05 removable HEPA hatch](M05_HEPA_SERVICE_HATCH.md), [visual layout](M05_HEPA_SERVICE_HATCH.html) and separate CAD. Widened-opening/casing examples are now a new fit branch, not approved dimensions. Flange/gasket/cover geometry and generic hardware locations added; real mechanisms, drop retention, compression and stiffness remain unknown.

Latest decision sheet: [weight and service-access sensitivities](M03_WEIGHT_SERVICE_DECISION.md). Outer casing dominates modeled weight; casing-only aluminium scenario saves 61.76 kg in a density calculation. Current 1 mm service gap is not robust to assumed allowances; door/seal hardware needs a real envelope. No material/dimension release or CAD revision is implied.

Newest fit option: [continuous frame around independent inner filter housing](M03_INDEPENDENT_HOUSING.md); 36 valid solids, zero nominal clashes, tight service margins recorded, weight not optimized. For the overall task rather than just CAD, use [six remaining build gates](BUILD_REMAINING.md). We are not yet fabrication-ready.

Latest calculation: [plate load-transfer and connection review](M02_PLATE_LOAD_REVIEW.md). Read-only partial material loads, equal-stiffness reaction sensitivities and six tests; no actual plate-strength approval. Segmented posts remain an unselected option. Next compare continuous supports around a separately sealed inner filter housing; avoid treating the appearance casing as the only possible pressure boundary.

Latest interface branch: [segmented capped posts at intact filter plates](M02_M03_SEGMENTED_INTERFACE.md), with [visual explanation](M02_M03_SEGMENTED_INTERFACE.html) and combined fit CAD. Zero checked nominal clashes; plates now lie in the support load path and require review. No structural or leakage approval; earlier continuous-frame findings remain historical evidence.

Newest fit check: [M02 frame routing and interface register](M02_FRAME_INTERFACES.md), [visual layout](M02_FRAME_LAYOUT.html) and separate FreeCAD/STEP. Eight unresolved post/plate clashes are explicitly recorded; no bulkhead holes cut or structural sections selected. Fan mounting, sealed support boundary and actual base still require design/review.

Latest mechanical finding: [M02 weight, support and stability screening](M02_WEIGHT_STABILITY.md). Partial CAD material inventory is 135.6 kg in the assumed steel scenario, not total tower weight. Actual component masses, frame/base, CG and support polygon are missing; compare lighter casing options with independent supports before fabrication. No structural PASS is claimed.

Latest physical detail: [M04 hollow transition/outlet study and pressure-basis check](AIRPATH_AND_PRESSURE_BASIS.md). Separate CAD generated; component loss coefficients remain assumptions. Short inlet/outlet lengths need OEM acceptance; no new performance claim or fabrication release.

Latest calculation step: [Fan-duty comparison and R02 candidate envelope branch](FAN_DUTY_DECISION.md). New OEM-backed comparison candidate improves modeled flow but does not satisfy every assumed loaded scenario; it is NOT selected. R02 height increase is an option study, not final dimensions.

Latest: [R01 cassette/intake development](CASSETTE_INTAKE_R01.md) adds eight intake apertures, illustrative gasket/seat/retainer interfaces and a lifted service sweep. [Supplier release questions](SUPPLIER_RELEASE_QUESTIONS.md) identify exact missing fan/filter data. R01 remains preliminary and unguarded; no OEM fan substitution or fabrication release.

Next step delivered: [Preliminary parametric 3D packaging CAD R00](PACKAGING_CAD_R00.md), native FreeCAD/STEP files and executed fit checks. Fan is still generic; intake/guards, seals and structure remain incomplete. This is not the former GEO_C air volume or a fabrication release.

New: [Visual schematic pack R00](SCHEMATICS.html) and [schematic register/packaging assumptions](SCHEMATIC_REGISTER.md). Includes tower section, pressure-tap airflow schematic and electrical/control functions; not released construction drawings.

User additionally requests a Dyson HushJet-inspired cylindrical option and government-project research. See [Cylindrical options and researched component families](CYLINDRICAL_OPTIONS.md). Rectangular GEO_C is no longer assumed to be the final physical shape; compare packaging alternatives before freezing CAD.

1. [Mechanical and filter plan](MECHANICAL_FILTER_PLAN.md): arrangement, seals, manufacturing and drawing checklist.
2. [Electrical and monitoring plan](ELECTRICAL_PLAN.md): safe system architecture and missing ratings.
3. [Preliminary tower BOM](TOWER_BOM.csv): candidate purchases; not order-ready.
4. [Build and test sequence](BUILD_AND_TEST.md): go/no-go checks and outdoor progression.
5. [Stakeholder brief](STAKEHOLDER_BRIEF.md): plain-language support request.
6. [Sources and tools](SOURCES_AND_TOOLS.md): official references and tooling choices.

## Immediate release blockers

Before cutting sheet metal: approve intended room/site, required measured airflow, noise target, exact fan/filter dimensional drawings, loaded pressure budget, enclosure mass/stability, and mechanical assembly drawings. Before energizing: approve protection, wiring, earthing, guarding and commissioning tests. A reasonable budget is not a substitute for these decisions.

No purchases, installation, new CFD, final CAD or electrical certification are implied by this planning package.

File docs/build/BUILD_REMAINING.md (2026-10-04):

# How much remains?

## Current D01 handoff — 5 October 2026

Room-duty supplement: the [updated shareable delivery](../../reports/shareable_20261005/README.md) adds an adjustable indoor room/scenario calculator, scale person and particle-target explanation. The example25 m2 room/2.8 m needs322.4 m3/h particle-cleaned flow for90% reduction in30 min, greater than the assumed300 m3/h airflow screen even with perfect capture. These are ideal assumptions, not accepted requirements or measured duty. Existing recorder/decay tools and templates are now bundled for the technical team. T01 site/target agreement and all physical/mechanical/electrical release gates remain OPEN; the room-software task alone is complete.

[IH02 is ready for the internal team](../../reports/prototype_d01/internal_handoff_20261005/START_HERE.md). Digital handoff preparation is complete: stakeholder explanation, engineering review with current drawings, source CAD/STEP/DXFs, consolidated parts register, funding worksheet, current pressure screen and test software. This is not completion of all remaining engineering. The register names exact remaining work: perforated guard/attachments and access, cabinet joint/stability checks, actual gasket/filter fit, hazard allocation, rated protective circuit/enclosure, commissioning and measured performance. These can be reviewed by the internal mechanical/electrical team without waiting for cable replies, while supplier-dependent interfaces stay open. Filter pressure/frame data, indoor room/targets, actual quotes and physical evidence are separate missing inputs. No fabrication or wiring release exists.

The full-size tower checklist and planning allowances below are historical context, not the current small D01 construction schedule. Do not infer a booked date or an approved procurement list from them.

Updated 3 October 2026. This is a build-readiness checklist, not a progress percentage or a guaranteed schedule.

## Short answer

### Build-start priority — 3 October 2026

We should now prioritize external component evidence and workshop quotations over more generic study branches. There are **three release gates before full-tower construction**, not a requirement to finish outdoor/network research first: exact requirements/components, mechanical release, electrical release. Outdoor development follows the indoor prototype; it must not silently delay or be claimed by the indoor build.

**Time planning allowance, not a confirmed estimate:** reserve roughly **4–8 weeks from receipt of usable OEM information and availability of qualified services/parts** for a first safely commissioned indoor prototype and initial measurements. Illustrative allocation: 1–2 weeks for component-specific design/review, 2–4 weeks for fabrication/assembly/commissioning, and 1–2 weeks for initial indoor measurements. These are planning placeholders chosen for coordination, NOT quoted turnaround or a commitment by the assistant/workshop. They exclude unknown supplier-response/procurement delays, major redesign and outdoor validation. Reviews/tests can uncover rework; repeated validation may take longer. No start or completion date is booked.

| Start priority | Use the existing package | Exit evidence / who acts |
|---|---|---|
| A — component information and quotes | [Fan selection brief](FAN_SELECTION_BRIEF_R00.md), [filter supplier questions](SUPPLIER_RELEASE_QUESTIONS.md) | Exact supported fan/filter proposals, matched curves/manuals/drawings/masses, quotes and lead times; supplier replies obtained by authorized team contact |
| B — actual place and acceptance targets | [No-lab route](NO_LAB_BUILD_ROUTE.md), [funded scopes W02–W04](FUNDED_WORK_PACKAGES.csv) | Indoor premises/room dimensions, supply/site facts, accepted flow/noise and available qualified review/workshop scope; user/team confirms |
| C — fabrication-ready core | Existing CAD studies, [closure package](M05_CLOSURE_REVIEW_PACKAGE.md), [electrical sequence](CORE_CONTROL_SEQUENCE.md) | Assistant produces component-specific assembly/support/seal/base/guard and electrical drafts; qualified review resolves issues and releases scope |
| D — authorized build and test | Work packages W03–W08 | User authorizes released orders/services; workshop assembles; competent inspection/commissioning and actual data recorded |

A and B can proceed in parallel. C uses their verified inputs; D must not bypass C. Supplier requests are prepared but NOT SENT; no reviewer/workshop booked and no parts ordered. The current fan comparison still lacks confirmed loaded-duty capability. A new assumed fan envelope cannot close this dependency.

What may start earlier with a separate suitable scope: quotation discussions, workshop design/manufacturability review, non-operating packaging mock-ups and isolated low-voltage instrument setup. Do not cut final structural/pressure-boundary parts, improvise mains wiring or energize an unreviewed fan/filter assembly from current study files. Separate component-only work needs its own appropriate safety/release scope.

Immediate next real-world action: obtain **fan/filter selection responses and a combined review/fabrication/commissioning quote**, while confirming the indoor premises. The assistant continues preparing/revising drawings and calculations; the optional ENTC friend is not a prerequisite. More presentation software, solar, carbon research and a decorative cylinder are not the current critical path. Keep necessary guards, enclosure, seals and supports in the core.

Current delivery basis: funding only from college/NGO; no college lab dependency. Assistant prepares digital design; ENTC reviewer optional/unconfirmed. Obtain required qualified physical services commercially. See [no-lab execution plan](NO_LAB_BUILD_ROUTE.md).

We are in **design development**. The idea, initial CAD, screening calculations and functional plans exist. We are NOT yet ready to send final drawings for fabrication. No complete physical prototype has been built or tested.

There are **six major gates still open**. They overlap in effort; they are not six equal-sized tasks. Gates 1–3 must be closed before releasing the complete tower for fabrication/assembly. A controlled component-only bench test may have a separate reviewed scope, but is not authorized by this checklist.

| Gate | Already available | Still required to close it | Who/input needed |
|---|---|---|---|
| 1. Requirements and component freeze | Indoor-first direction, fan/filter candidates, draft supplier questions, clean/loaded sensitivities | Actual test room/site, accepted flow/noise targets, exact purchasable fan/filter, OEM drawings/curves/orientation/masses, real quotes | Team + suppliers; assistant can compare documented responses |
| 2. Mechanical design release | Round packaging, cassette/frame branches, new independent housing fit, weight/load sensitivities | Pick architecture; resolve tight service margins; detail seals/doors/guards, fan mounts, frame/base/joints; full mass/CG, structural/stability checks; drawings and manufacturing BOM | Assistant prepares; paid qualified mechanical reviewer + fabricator, with OEM inputs |
| 3. Electrical/control release | Functional electrical plan and monitoring intent | Exact OEM power/control wiring, rated protection/isolation/earthing, enclosure/cable design, safety functions, inspection/commissioning plan | Qualified electrical reviewer/assembler; assistant can document verified design, not approve mains safety |
| 4. Procurement, build and commissioning | Preliminary BOM and test sequence | Confirm funding/quotes, order released parts, fabricate/assemble, inspect mechanically/electrically, verify guards/seals and safe operation | Team + vendors + qualified workshop staff |
| 5. Indoor physical validation | Digital airflow/particle evidence and proposed test plan | Measure actual airflow, filter/guard losses, installed bypass, PM reduction under controlled conditions, noise, power and maintenance behavior; report limitations | Safe controlled room, instruments, qualified supervision; assistant can analyze recorded data |
| 6. Outdoor pilot and scale-up | Outdoor goal and chain-of-local-zones concept | Site/weather/anchoring/public safety design; approved pilot; wind/background/nearby PM monitoring; establish any real benefit before tower spacing/network claims | Site permission + relevant reviewers + field testing |

**None of these gates is closed by a “no clash” CAD result or passing unit tests.** Digital testing is not a physical tower demonstration. A stakeholder presentation can explain current progress now, but must not call the design construction-ready or claim a proven outdoor bubble.

## What can move forward here without pretending missing facts exist

- Refine manufacturability/service envelopes, compare material/weight options and prepare reviewer-ready connection concepts.
- Maintain the full pressure budget and compare exact OEM duty data once supplied.
- Develop low-voltage data logging and instrument documentation separately from mains safety functions.
- Prepare a consolidated design-review package and update this checklist when actual evidence closes an item.

## Inputs needed from outside the CAD work

The existing [draft supplier questions](SUPPLIER_RELEASE_QUESTIONS.md) are ready for team review, but have NOT been sent. Obtain exact fan and filter drawings/curves/masses and confirm allowed orientation. Quote qualified mechanical/electrical review services; optional ENTC feedback is not a guaranteed resource or a substitute for required competence. Provide actual indoor room dimensions and outdoor pilot location when known. Pune/Hyderabad/Mumbai are possibilities, not confirmed premises.

No fixed budget ceiling or demonstration date has been given. Availability, reviewer turnaround and workshop capacity are UNKNOWN. We therefore cannot honestly promise a number of days/weeks or a completion percentage yet. More CAD branches cannot replace missing OEM data or engineering review.

## Current next step

Use [the closure supplier/workshop package](M05_CLOSURE_REVIEW_PACKAGE.md) and response sheet to obtain actual hatch hardware and gasket data. This request is prepared, NOT sent. Mechanical review must select the arrangement before another detailed closure CAD branch. Other tasks can proceed independently, but completing this worksheet alone does not close any whole-tower gate.

New [M05 HEPA hatch branch](M05_HEPA_SERVICE_HATCH.md) models the widened service opening, flange/gasket space and cover. Its fit check does not close mechanical release: actual latch/catch CAD, gasket data, cover retention/stiffness and mounting/seal details must be resolved with suppliers/reviewers. Prefilter closure remains preliminary; all six gates remain open.

Latest [weight/service comparison](M03_WEIGHT_SERVICE_DECISION.md) prioritizes lighter cosmetic casing and real flange/latch/service envelopes. A 129.52 kg partial hybrid scenario and example 645 mm opening / 980 mm casing are calculations only, not selected specifications or edited CAD. Existing tight margins remain open.

Use the [independent inner housing study](M03_INDEPENDENT_HOUSING.md) to resolve service/flange tolerances and evaluate lighter casing/frame options; keep architecture selection open until reviewer and OEM inputs arrive. Do not order metal to the study's assumed 2/5 mm gauges or 35 x 35 x 3 mm profiles.

Physical prototypes built: **0 in the reviewed records**. Complete physical performance tests: **0**. Outdoor radius/cleaning percentage/network spacing: **NOT PROVEN**. Purchases or supplier messages in this build transition: **none**.

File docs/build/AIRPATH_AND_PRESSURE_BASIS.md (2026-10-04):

# Air path, transition and pressure accounting — M04 study

2 October 2026. PRELIMINARY. No component selection, fabrication release or new CFD.

## Physical work completed

Created three hollow CAD parts in a separate fit-study document: square-to-round transition, short inlet neck and straight circular outlet. This develops the R02 candidate layout without changing R00/R01/R02. It is not fitted to detailed OEM fan CAD.

Files: `cad/packaging/AQI_M04_Airpath_STUDY.FCStd`, `AQI_M04_Airpath_NOT_FOR_FABRICATION.step`, `M04_AIRPATH_AUDIT.json`; configuration `cad/parametric/airpath_m04_study.json`; generator `scripts/geometry/create_airpath_study.py`.

```text
          Required outlet guard: not selected or modeled
                            ↑
        Circular outlet: 315 mm clear bore ASSUMED, 200 mm long
                            ↑
                Candidate fan: not modeled here
                            ↑
        Short neck: 315 mm clear bore ASSUMED, 10 mm long
                            ↑
       Square-to-round transition: 563 mm -> 315 mm, 215 mm high
                            ↑
             Sealed clean plenum / air above HEPA
                            ↑
             Retained and sealed HEPA cassette
```

Transition base z=965 mm is 20 mm above the illustrative R02 retainer top. Its top is z=1180 mm; neck ends at z=1190 mm. Outlet starts z=2015 mm and ends z=2215 mm. These coordinates align with the bounding-envelope study, not verified actual fan inlet/outlet axes. A flange, mount or terminal enclosure may change the fit.

315 mm is an assumed **internal flow diameter**. The S&P drawing's 312 mm connection dimension is not proof of a 312 mm internal bore. Spigot wall, mating tolerances, clamp and gasket must be established by an actual connection drawing. Do not machine an adapter from these assumptions.

CAD uses 2 mm profile offsets, not uniform normal wall thickness or developed sheet-metal panels. Regenerate from the JSON for profile changes; the shapes are generated snapshots, not spreadsheet-linked parts. FreeCAD checks found three valid solids; native file reopened and STEP reimported with three valid solids. No structural, service, leakage or installed aerodynamic validation was performed.

## Why we are not adding a narrow jet nozzle yet

A simple same-bore outlet is the first comparison baseline. A smaller nozzle raises discharge velocity and can increase required fan pressure and noise. Entrainment mixes surrounding air but does not mean that air has passed through the filter. We can compare outlet shapes later; there is no evidence yet for a Dyson-like outdoor bubble.

At assumed 1,300 m3/h and density 1.2 kg/m3, a 315 mm clear duct has mean velocity 4.63 m/s and velocity pressure 12.88 Pa. These are arithmetic screening values, not measured fan velocities.

## Pressure basis: what must be matched

[AMCA's fan-curve explanation](https://www.amca.org/educate/articles-and-technical-papers/amca-inmotion-articles/straightening-out-fan-curves.html) distinguishes fan total pressure, static pressure and outlet velocity pressure. Use the manufacturer's actual stated area and test definition, not an arbitrary casing dimension.

For the simplified ambient-intake to free-discharge system considered here, with uniform flow and no external static backpressure:

```text
Fan total-pressure requirement
    = sum of internal irreversible losses + terminal velocity pressure

Fan static-pressure requirement
    = fan total-pressure requirement - fan outlet velocity pressure

Therefore:
    static duty = internal losses + terminal VP - fan outlet VP
```

When the fan outlet and final discharge have the same effective flow area, their velocity-pressure terms cancel. In that special case the fan static duty is the internal irreversible loss sum. Adding the free-jet velocity pressure again to that sum while using the static fan curve would double-count it. Guard/duct/transition losses still remain.

If the outlet area changes, keep both terms and include the new fitting's loss. Static pressure difference measured between fan taps is not automatically AMCA fan static pressure; inlet velocity and measurement planes matter. Nonuniform flow, external pressure, swirl and installed fan effects require additional analysis. We have not verified the actual OEM flow area or test-installation match, so this does not certify a selection.

Earlier 50/100 Pa hardware inputs are broad sensitivity assumptions, not reconciled measured system-static resistance. Prior fan intersections remain illustrative. This clarification does not silently turn them into confirmed performance.

## Component-by-component loss sensitivity

Run `python scripts/analysis/airpath_loss_screen.py`. It uses an assumed 70% intake free area, 315 mm clear round duct, and explicitly ASSUMED coefficients/friction factors. The numerical endpoints are study inputs, **not evidence-based design bounds**.

| Component | Low-input scenario Pa | High-input scenario Pa |
|---|---:|---:|
| Combined intake entry + guard | 14.92 | 39.78 |
| Square-to-round transition | 1.29 | 6.44 |
| Outlet guard | 12.88 | 38.65 |
| Connections/joints | 1.29 | 6.44 |
| Equivalent fan installation effect | 0 | 25.77 |
| 210 mm modeled straight round length | 0.16 | 0.30 |
| Total hardware sensitivity | 30.53 | 117.38 |

The transition coefficient is referenced to round-throat velocity; intake coefficient to assumed guard-passage velocity. These coefficients were NOT obtained from an OEM fitting curve. The calculation exposes which data we need; it does not validate a smooth-looking CAD loft. Values outside this range are possible.

With same-area fan/terminal cancellation, adding the previous illustrative filter assumptions gives:

- Clean filter scenario: approximately 163–250 Pa required static duty at 1,300 m3/h.
- HEPA 2x resistance plus prefilter 80 Pa-at-reference scenario: approximately 326–413 Pa at the same flow.

These are not new fan operating points or approved dirty-filter thresholds. A larger intake/low-loss guard can help; it does not remove the HEPA resistance. Rain louvres, silencers, bends and optional carbon are absent; add their losses if introduced.

## Installation-effect issue still unresolved

The inlet neck is only 0.032 duct diameters long, and the outlet is 0.635 diameters. [AMCA's system-effect guidance](https://www.amca.org/educate/articles-and-technical-papers/amca-inmotion-articles/mitigating-system-effect-to-optimize-fan-performance-efficiency.html) discusses nonuniform outlet flow and an illustrative 2.5-diameter outlet-length rule of thumb under its stated conditions. It is not a universal requirement for this particular mixed-flow fan.

Do not assume a compact 200 mm outlet reproduces catalogue performance. Ask the selected OEM to accept the inlet contraction, straight lengths, guards and outlet arrangement, or provide correction/installed testing. Simply adding long ducting may make the tower impractically tall; another fan architecture or layout could be preferable. [DOE's fan guidance](https://betterbuildingssolutioncenter.energy.gov/better-plants/fans) also emphasizes managing inlet/outlet flow uniformity.

## Required decisions before the next mechanical release

1. Fix minimum useful flow from the actual indoor test-room volume and a mentor-approved demonstration target; define the outdoor pilot setting separately.
2. Obtain selected fan flow area, installation geometry, numeric curve and inlet/outlet guidance. Do not select a fan only because it fits the cylinder.
3. Select commercial or engineer-reviewed guards with documented free area, loss and access protection; hole size alone does not establish safety.
4. Replace coefficient guesses with supplier data, defensible correlations or controlled measurements. Reconcile pressure basis at named planes.
5. Integrate adapters, supports, flanges and service access into the assembly. Confirm sheet-metal manufacturability and approved seals.

Final fan choice, exact wiring, protection ratings and fabrication sheets remain unreleased. The next useful input is actual room dimensions and the intended outdoor location type, rather than another assumed coverage circle.

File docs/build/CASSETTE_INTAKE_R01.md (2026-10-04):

# Filter cassette and intake development — R01

2 October 2026. PRELIMINARY, NOT FOR FABRICATION. Current model: `cad/packaging/AQI_Cylindrical_Packaging_R01.FCStd`. R00 remains unchanged.

## What changed physically in the CAD

Eight radial intake openings are now cut into the lower shell. The HEPA bulkhead has an illustrative supporting ledge rather than a full-size hole. A gasket envelope lies between the assumed filter-frame underside and this ledge. A separate removable top hold-down ring shows the retention concept. Service space assumes removal of this ring and a small filter lift before sliding out.

This is still an interface study: the actual candidate filter's frame profile, gasket position, allowable mounting orientation and clamp loads are UNKNOWN. The shape does not prove sealing, guard safety or air-cleaning performance.

## M03-R01: assumed filter seat section

```text
                       CLEAN SIDE / FAN SUCTION
                removable hold-down / retainer
                ↓ reviewed clamp force (UNKNOWN)
             ┌───────────────────────────────┐
             │ filter frame     filter media │  outer size 593 mm candidate
             └───────┐                ┌──────┘
                     ▓ gasket         ▓          illustrative envelope only
        sealed plate ━━━━━┓      ┏━━━━━ sealed plate
                           ↑ air
                         DIRTY SIDE

The full-width plate closes the route around the filter.
Support and clamping act on the filter FRAME, never fragile media.
```

Illustrative seat opening: 563 mm square; assumed frame/ledge allowance 15 mm per side. Gasket envelope: 583 mm outer, 563 mm inner, 3 mm installed height. Retainer: 633 mm outer, 563 mm inner, 5 mm modeled thickness. These are not supplier dimensions or fabrication tolerances. A 3 mm installed envelope is NOT a gasket compression requirement; uncompressed size and material curve are unknown.

Check that the actual clear media area is not obstructed by this frame/retainer. An OEM frame with a different seal plane can invalidate this entire arrangement. Ask for an approved installation drawing before machining or cutting the cassette.

## Retention load: why the seal cannot rely on gravity

Pressure below the horizontal filter is higher than above it in this upward-flow arrangement. That pushes the filter upward, tending to unload the lower gasket. Screening pressure force is ΔP x projected area. At an explicitly assumed 500 Pa across a 593 mm square envelope, force is about 176 N (approximately 18 kg-force). This is NOT a measured operating pressure, clamp rating or design load.

The reviewer must combine pressure loading, filter mass, gasket seating/compression, frame stiffness, handling loads and appropriate factors. Determine failure behaviour during blockage and fan operation. Do not divide 176 N by four and buy four clamps: compression load, force distribution and actual pressure limits still need data. The retaining arrangement requires positively retained, reviewed hardware and should not depend on the service door alone.

## Safe service sequence to develop

Isolate power and verify fan stopped. Remove/open the reviewed service door; release/remove the retainer; lift filter off its gasket before sliding onto a rated tray/support. In this study the lift is 5 mm, an ASSUMPTION. Do not drag the gasket sideways under compression. Refit, inspect the seal, reclamp according to the supplier method, close access and conduct the specified integrity checks before operation.

Retainer fasteners, lift mechanism, rails, tray, filter mass, handling method and door hinges/latches are not designed. The geometric removal sweep excludes the retainer because it has to be removed first; it is not proof that maintenance is safe or convenient.

## Intake sizing screen

Eight assumed 160 x 140 mm openings provide 0.1792 m2 total projected gross area. The actual curved surface area differs slightly; guard/louvre clear area is smaller still.

At the illustrative 1,300 m3/h screening flow:

| Assumed guard free-area fraction | Effective area m2 | Mean passage velocity m/s | Dynamic pressure Pa, rho=1.2 assumed |
|---|---:|---:|---:|
| 100%, no guard (not safe to operate) | 0.1792 | 2.02 | 2.44 |
| 70% | 0.12544 | 2.88 | 4.97 |
| 50% | 0.0896 | 4.03 | 9.75 |

Dynamic pressure is NOT the guard pressure drop. Loss = K x dynamic pressure only with a defensible coefficient for the actual geometry, or use the supplier's measured loss curve. Select a finger-safe guard, account for dust/loading and rain protection, and recheck the full fan/system operating point. The model currently has unguarded openings and is not approved for use.

## Executed CAD checks

Valid generated geometry; no positive-volume clashes among twelve exported envelope objects; nominal lifted HEPA sweep clears the shell, gasket and bulkhead after removal of the retainer. Diameter expression propagation passed. Native file was reopened; STEP was reimported with twelve valid solids. These checks do not cover actual hardware, stress, leakage, airflow or weather resistance.

Source and audit: `cad/parametric/cylindrical_packaging_r01.json`, `cad/packaging/PACKAGING_R01_AUDIT.json`. Reproduce:

```powershell
& 'D:\Applications\FreeCAD 1.1.3\bin\python.exe' scripts/geometry/create_cylindrical_packaging.py --config cad/parametric/cylindrical_packaging_r01.json
```

Derived R01 files are replaced on regeneration; save intentional manual edits under a different revision first. The viewing macro now opens R01. For the preserved R00 file, manually open it and hide the construction tools.

## Official source checks and remaining data

Reviewed 2 October 2026:

- [Camfil CamSafe installation manual](https://www.camfil.com/dam/files/21962/1672906/Instruction_CamSafe-2-Installation-and-Operating-Manual-ENG.pdf): illustrates engineered filter-seat integrity provisions and specific gasket/housing combinations. It does not approve our fabricated cassette.
- [Camfil GlidePack housing family](https://www.camfil.com/en-ca/products/housings-frames--louvers/ducted-housing/glidepack): provides commercial examples of side-access service, flat sealing edges and pressure test ports. Its load/pressure figures are not our design specifications.
- [Systemair AC fan instruction manual](https://shop.systemair.com/upload/assets/202341_FANS_INSTRUCTIONS_CE__A016_.PDF) distinguishes fan families and wiring diagrams; [EC-family manual](https://shop.systemair.com/upload/assets/EC_FANS_OPERATION_AND_MAINTENANCE_INSTR__206268_CE_A017_20190426_193821977.PDF) includes KVO EC models. Neither check establishes the exact historical KVO 250/L unit's purchased geometry or availability.

Do not use unrelated fuel-cell filter gasket instructions as HEPA requirements. Exact fan and filter data requests are in [supplier release questions](SUPPLIER_RELEASE_QUESTIONS.md). No requests sent and no parts purchased.

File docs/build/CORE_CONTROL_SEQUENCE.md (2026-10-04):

# Fan/filter core — operating and fault plan R00

3 October 2026. PRELIMINARY FUNCTIONAL DESIGN: NOT RELEASED FOR WIRING OR ENERGIZING.

## In simple words

Press START to run the tower and STOP to stop it. After a power cut or a protective trip, it must not restart by itself. For filter changes, switch off, isolate and lock off the electrical supply; a stopped fan or a zero-speed setting is not proof that it is safe to touch.

The first prototype uses local controls and an OEM-compatible manual speed setting. The laptop records measurements only. No app, automatic PM-based speed changes, remote start or custom safety PCB is proposed for this first build.

## Evidence labels

- FACT / user basis: indoor trial first; college/NGO funding only; ENTC review optional. The assistant prepares this design, with qualified physical review/assembly/testing before use.
- DETECTED: historical AC fan data and a different S&P EC comparison candidate exist. Neither gives an approved wiring design for a selected delivered unit.
- RECOMMENDATION: the behavior below is the design requirement to implement and verify, not a description of installed hardware.
- UNKNOWN: exact fan SKU, delivered manual, supply conditions, motor protection/reset behavior, switching architecture, coast-down time, access arrangement and component ratings.
- Physical implementation and tests: NOT DONE. All six overall build gates remain open.

See the [functional visual](CORE_ELECTRICAL_FUNCTIONS.svg). It has no terminal numbers, conductor sizes or device ratings. It is a starting point for E01/E02, not their release.

## Proposed operating sequence

| State | Meaning | Transition requirement |
|---|---|---|
| ISOLATED | Maintenance isolation established and verified by the competent person | Restore only after work complete, covers/guards secured and tools removed |
| OFF / NOT READY | Supply may be present; start inhibited | Resolve missing permissives; OFF is not safe-access permission |
| READY | Verified permissives available; no run request | Fresh local START action, after START has been released |
| RUN REQUESTED | Reviewed controls request fan operation | Confirm actual operation separately; command is not rotation proof |
| STOPPING | Run request removed; fan may coast | Do not allow hazardous access based on a timer guessed in software |
| TRIPPED | Protective condition latched; start inhibited | Resolve cause, verify permissives, deliberate RESET, then a separate fresh START |

Power restoration leads to OFF, not RUN REQUESTED. Closing a door, clearing a fault or pressing RESET alone must not start the fan. A START button held during restoration/reset must be released before a new start is accepted. STOP or a protective inhibit takes priority over START.

These are acceptance requirements for the reviewed hardware architecture. A Python script, laptop, microcontroller or ordinary relay diagram is not their safety implementation. Protective function selection, diagnostic coverage and required reliability remain a qualified risk-assessment task.

## Cause and effect

| Event | Required response / operator action | Unresolved implementation |
|---|---|---|
| Supply lost and restored | Run request cleared; fresh local start required | Undervoltage/restart prevention and OEM internal restart behavior |
| Local STOP | Remove run request; indicate stopping if appropriate | OEM-approved stop method and actual run-down |
| Service access opened or protective permissive lost | Inhibit start; initiate reviewed protective response | Which doors expose hazards; interlock/guard locking and response architecture |
| Guard closed again | Remain stopped; deliberate reset if protective trip, then fresh start | No automatic restart from door closure |
| OEM thermal/motor protection operates | Preserve OEM protection; stop/inhibit through reviewed arrangement; investigate cause | Exposed contacts/status, internal auto-reset and external trip detection UNKNOWN |
| Protective input missing, broken or inconsistent | Do not treat UNKNOWN as permission to run | Detection, fail-safe behavior and fault tolerance must be designed, not assumed |
| Speed command lost/disconnected | Behavior must be resolved and verified before release | Do not assume 0 V, open circuit or communication loss means stopped |
| Fan fails to respond to run request | Operator stops test; inspect only under isolation | Actual run feedback and detection timeout UNKNOWN; no invented RPM terminal |
| Filter pressure rises | Record and flag only against an approved maintenance threshold | No inherited 80/100/111 Pa automatic trip; use filter limits and measured duty |
| PM sensor/logger/USB connection fails | Mark measurement invalid; suspend performance-data trial | Logger failure must not disable independent protection; no automatic safety action claimed |
| Emergency stop, if required by risk assessment | Reviewed protective stopping; reset must not restart | Need, location, stop category and reset architecture UNKNOWN |

A door switch alone does not prove safe access while the impeller coasts. Determine whether fixed guarding, guard locking or another validated arrangement is required. Motor protection may reset internally: do not assume it supplies an external trip contact or prevents restart. That behavior must be addressed for the selected unit.

## Controls and indicators to design

Local START, STOP and deliberate trip RESET are proposed functions, not selected parts. Include a separately identifiable lockable service isolator. Emergency-stop provision is a risk-assessment decision, not silently equated with normal STOP.

- Label a command indication **RUN REQUESTED**, not **FAN RUNNING**, unless actual operation feedback is verified.
- A power lamp can indicate its monitored point only; a dark lamp never proves isolation.
- Keep the speed reference separate from restart permission and service isolation.
- Keep monitoring powered separately from fan control where practical; define every supply affected by maintenance isolation. Avoid backfeed through USB or separately powered equipment.
- Keep protective-earth continuity independent of controls; never switch or fuse PE. Determine actual fan class and bonding requirements from the supplied unit and the enclosure design.

## Electrical interfaces — not a terminal schedule

The [interface register](CORE_ELECTRICAL_INTERFACES.csv) lists functions and missing evidence. All physical terminal IDs, sizes and ratings remain UNKNOWN. It must not be used as assembly instructions.

E01: source, isolation, protection and branch single-line from verified site inputs.
E02: selected fan/OEM controller plus reviewed stop/restart/protective circuits.
E03: exact terminal-to-terminal and cable schedule after E01/E02 review.
E04: enclosure layout, segregation, bonding, glands and service access.
E05: cable/protection/switching selection using actual supply fault conditions, motor inrush/leakage and installation environment—not nominal watts alone.
E06: physical commissioning procedure with reviewer-approved methods and recorded results.

## Proposed commissioning witness cases

All are NOT EXECUTED. Qualified personnel must choose safe test methods; do not induce live faults or defeat guards. Some cases can be verified by document/design review plus controlled simulations rather than deliberately damaging equipment.

| Case | Acceptance to demonstrate |
|---|---|
| C01 | Inspection confirms approved components, guards, terminations and segregation |
| C02 | Applicable bonding, insulation, polarity and protection tests recorded |
| C03 | Power applied with no START: no run request / unintended movement |
| C04 | Normal start, OEM speed adjustment and stop operate as approved |
| C05 | Power interruption/restoration does not automatically restart |
| C06 | START held through power restoration cannot automatically restart |
| C07 | Simultaneous START/STOP resolves to stop |
| C08 | Access protective function prevents start and gives the approved stopping response |
| C09 | Closing access alone or RESET alone does not restart |
| C10 | START held through reset requires release and a new deliberate action |
| C11 | OEM trip/reset behavior cannot create unintended restart |
| C12 | Specified protective input faults have the reviewed response |
| C13 | Speed-command loss behavior matches approved design |
| C14 | Logger/USB failure cannot defeat protection; data marked invalid |
| C15 | Service isolation covers identified supplies; run-down/access and restoration verified |

Do not record PASS until there is a dated result, exact assembly revision, method, instrument details where applicable, reviewer/operator and evidence reference. This checklist does not establish compliance or replace risk assessment.

## Sources checked 3 October 2026

- [S&P TD-SILENT ECOWATT family installation manual](https://statics.solerpalau.com/media/import/documentation/H13-TD-SILENT-ECOWATT-NOTICE.pdf): family reference found, not the confirmed supplied-unit manual. Variants differ; obtain the actual article/revision before using any diagram. No terminal assignment or protection rating copied into this pack. A subsequent fetch timed out; no new local manual archive is claimed.
- [HSE machinery safety introduction](https://www.hse.gov.uk/work-equipment-machinery/introduction.htm): used for general guarding, safe maintenance isolation, competent work and restart-risk review. UK guidance, not an Indian compliance determination.

Next release input: exact fan and matching OEM instructions **plus** actual site/supply facts. Prepare rated E01–E05 from those inputs and obtain qualified review before assembly; do not choose a fan solely to finish the circuit. The [fan-duty comparison](FAN_DUTY_DECISION.md) still has loaded-duty limitations.

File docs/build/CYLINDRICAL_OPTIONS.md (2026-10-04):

# Cylindrical tower: Dyson inspiration and outdoor lessons

2 October 2026. User-requested design alternative. PRELIMINARY comparison; no concept frozen, no fabrication CAD generated.

## What we can learn from HushJet

[Dyson's official HushJet page](https://www.dyson.com/air-treatment/air-purifiers/hushjet) describes 360-degree filters and a shaped high-velocity discharge that entrains surrounding air. It describes passive electrostatic particle media, not a powered ionizer. These are manufacturer descriptions of its indoor product, not measured results for our project.

Useful principles: intake distributed around a body, accessible replaceable cartridges, sealed clean/dirty compartments, and careful outlet/noise design. Do not copy the proprietary nozzle geometry or assume scaling its appearance produces the same performance. Entrained room air increases mixed jet flow, not filtered clean-air delivery. A narrower nozzle can raise pressure loss and noise; it is not free additional purification.

## Three practical options

| Option | What it looks like | Build advantage | Main drawback |
|---|---|---|---|
| A: cylindrical outer shell, standard panel-filter core | Rounded metal exterior around replaceable rectangular cassette | Standard documented filters; quickest service/procurement route | May be wide; circular appearance does not establish true radial filtration |
| B: polygonal bank of panel filters | Multiple flat cassettes around central clean plenum and fan | Radial intake using standard panels; more filter area | More seals, cassettes and loaded-flow balancing; airflow/structure redesigned |
| C: genuine cylindrical cartridge | Radial flow through ring-shaped filter into central core | Compact coherent circular architecture | Need suitable documented cartridge curves, leak-tight end seals and dependable replacement supply |

RECOMMENDATION: compare A and C first; keep B if standard panel suppliers offer a convincing low-loss arrangement. Do not select C just because it looks most like Dyson. Do not stretch the previous GEO_C model into a cylinder and reuse its results.

If a 593 x 593 mm square filter is placed across a circular cross-section, its diagonal alone is about 839 mm. The shell must be larger after clearance, frame and wall allowances. That geometric constraint applies only to this orientation; an upright cassette layout must be checked separately in the assembly. A small cosmetic cylinder will not contain the present candidate automatically.

For a radial cylindrical cartridge, gross cylindrical area is pi x diameter x active height. Example assumptions D=0.6 m, H=0.6 m give 1.13 m2 and about 0.32 m/s gross radial face velocity at 1,300 m3/h. This is a sizing illustration, not a filter selection: pleated media area, core restrictions, end caps and supplier pressure curves determine real behaviour.

Conceptual air route (not an approved arrangement):

```text
               guarded outlet
                     ^
              reviewed fan module
                     ^
               clean central path
                     ^
 intake around body -> coarse filter -> sealed particle filter
              base + isolated electrical compartment
```

For the outdoor version, outlet direction/height is an open design question. A jet upwards may mix or escape rather than benefit breathing height; low outlets can recirculate or create public-access hazards. Compare configurations using site wind and breathing-height measurements, not marketing resemblance.

## Government projects: what was established

[PIB's 29 July 2024 statement](https://www.pib.gov.in/Pressreleaseshare.aspx?PRID=2038298&lang=2&reg=48) lists government-supported trials including NEERI traffic-junction purification units, bus-roof filtration and an IIT Bombay/Tata Projects smog tower. The tower involved substantial infrastructure and operating costs; the announcement is not proof that any outdoor purifier succeeds.

The [Delhi Economic Survey 2025–26](https://delhiplanning.delhi.gov.in/sites/default/files/2026-03/economic_survey_english_0.pdf), printed page 127 (PDF page 140), says the Connaught Place pilot became operational in September 2021, was assessed by IIT Bombay, and had limited effectiveness because the filtered-air jet's influence was too small. Its narrative and tabulated distance summaries differ; do not extract a guaranteed 500 m radius from it. No numerical tower efficiency is transferred to our design.

Our inference: copying the scale or appearance of a government tower is not sufficient. Keep the first outdoor objective local and testable: useful reduction at defined occupied points, under recorded wind, for reasonable energy and maintenance. Source control remains important. A chain is a hypothesis to test after one unit demonstrates benefit.

## Real component families to investigate — NOT an order list

| Function | Public OEM candidate/source | What still has to be obtained |
|---|---|---|
| Circular duct fan | [Systemair K AC/EC family](https://www.systemair.com/en/products/fans/duct-fans/circular-duct-fans/k), [India catalogue/contact](https://www.systemair.com/en-in/products) | Exact India SKU, duty curve with loaded filters, envelope, acoustics, control diagram and quote |
| Centrifugal EC blower | [ebm-papst air-purifier fan portfolio](https://www.ebmpapst.com/gb/en/industries/ventilation/air-purifiers.html) | Select exact RadiCal/other model at duty point; inlet/mounting design and protection requirements |
| Particle filter | Existing Freudenberg panel candidate as reference; request documented panel alternatives or cylindrical cartridge from qualified suppliers | Actual dimensions, multi-point clean/loaded curves, unit certificate, sealing and replacement availability; no suitable cylindrical HEPA SKU confirmed yet |
| Optional gas cylinder | [Camfil CamCarb family](https://www.camfil.com/en/products/molecular-filters/cylinders) | Gas-specific media and breakthrough/pressure data; these are molecular/carbon filters, NOT HEPA particle cartridges |
| Housing | Local folded/rolled metal fabricator | Assembly drawings, material/coating, structure and weather protection |

Do not buy Dyson domestic replacement cartridges for a much larger tower without documented compatibility, pressure curves and replacement strategy. Product-family existence does not establish local stock, price or suitability. No supplier contacted and no component ordered.

## Supplier data request to finish selection

Send only after team authorization: intended particulate-only prototype, indoor commissioning/outdoor future use, provisional screening flow 1,200–1,300 m3/h (not yet accepted target), and request quotes plus dimensional drawings. Ask for fan curves including efficiency/power/noise at the proposed complete-system duty, supported speed control and safety instructions; filter initial/terminal resistance curves, certification, dimensions, mass, end-seal/gasket details and replacement lead time. Ask vendors to propose alternatives if the selected fan cannot meet loaded resistance.

The final design must choose shape AND serviceable components together. Complete architecture choice before the manufacturing drawing release, not after purchasing incompatible parts.

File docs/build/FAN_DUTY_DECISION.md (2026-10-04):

# Fan duty and packaging decision — screening, not purchase release

2 October 2026. The practical question is: **will the fan still move enough air when filters and guards resist it?** Free-air flow is not the answer.

## Current decision

Do not freeze the old KVO 250 or the new comparison candidate for procurement yet. Compare at the required minimum airflow under an approved loaded-filter condition. Current 1,200–1,300 m3/h values are study targets, not an agreed room or outdoor requirement.

The new S&P TD-2000/315 SILENT ECOWATT is a useful documented candidate for comparison, not a selected replacement. Its [official catalogue](https://statics.solerpalau.com/media/import/documentation/EN_TD-SILENT-ECOWATT.pdf) provides static-pressure curves, a dimensioned drawing, 14 kg mass and maximum absorbed power 247 W. Published free-discharge flow is 1,660 m3/h. The upright main-drawing bounding envelope used here is 432 x 373 x 825 mm; it does not include verified mounting, cable-box, adapter or service clearances. Confirm exact India variant/availability.

## Reproducible loss assumptions

Pressure-basis qualification: read [M04 air-path and pressure accounting](AIRPATH_AND_PRESSURE_BASIS.md). Hardware numbers below are illustrative allowances, not a confirmed match to the fan static-pressure test definition. Exit velocity energy must not be double-counted; actual outlet areas and installed effects remain unverified.

Run `python scripts/analysis/fan_duty_screen.py`.

For each scenario, filter pressure scales linearly with flow (unvalidated extrapolation). HEPA clean reference 111.2 Pa at 1,332 m3/h comes from the historical partial CFD interpretation, not a measured new-cassette curve. Hardware allowance scales with flow squared. It replaces the old 3.8 Pa residual—adding both would double-count part of the same allowance.

| Scenario | HEPA resistance multiplier | Prefilter Pa at 1,332 m3/h | All hardware Pa at 1,300 m3/h |
|---|---:|---:|---:|
| Clean, moderate hardware | 1 | 25 | 50 |
| Clean, restrictive hardware | 1 | 45 | 100 |
| HEPA 2x, clean prefilter | 2 | 25 | 50 |
| HEPA 2x, loaded prefilter, restrictive | 2 | 80 | 100 |

Hardware includes intake/outlet guards, transitions, ducts and relevant discharge losses. These allowances are sensitivity inputs, not a measured breakdown. Loaded multiplier and 80 Pa prefilter scenario are not approved terminal-pressure settings. No carbon bed fitted.

## Calculated comparison

| Assumed condition | Historical KVO curve m3/h | S&P digitized curve m3/h |
|---|---:|---:|
| Clean, moderate hardware | 1,246 | 1,364 |
| Clean, restrictive hardware | 1,177 | 1,274 |
| HEPA 2x, clean prefilter | 1,132 | 1,229 |
| HEPA 2x, loaded prefilter, restrictive | 1,047 | 1,111 |

These are model intersections, not promised airflow. S&P curve points were visually read from the inspected manufacturer chart (printed page 194), not supplied as certified numerical data. A +/-25 Pa chart-reading sensitivity gives about 1,078–1,144 m3/h for the last scenario; this excludes the much larger uncertainty in losses/installation. KVO variant identity remains unresolved.

Preliminary fan-system intersections

## What this tells us

- A stronger comparison candidate helps, but even it falls below an illustrative 1,200 m3/h target in the restrictive loaded scenario. It is not yet evidence of adequate loaded duty.
- Maintaining 1,300 m3/h in that scenario requires about 395 Pa on the same pressure basis; candidate chart gives about 230 Pa there. Ask suppliers for a confirmed duty around 1,300 m3/h at 400 Pa as this scenario's benchmark—not as a newly proven product requirement.
- At that benchmark, Q x pressure is about 143 W of air power. Electrical input is higher and depends on efficiency and installation. A fan's wattage alone does not prove that duty; 247 W is a catalogue maximum, not predicted tower consumption.
- Larger filter area or lower-resistance fittings may reduce required head. A different fan is another route. Do not simply increase speed without OEM limits, noise/power assessment and a curve.
- Control should manage an agreed useful flow range; pressure alone cannot identify delivered flow unless calibrated against the assembled system. Maintaining speed is not the same as maintaining airflow.

Before finalizing, reconcile fan static versus total pressure and terminal velocity losses for the actual measurement planes. The circular open-plenum tower is not necessarily the manufacturer's test installation. Agree maintenance thresholds from OEM limits plus measured flow, not an arbitrary filter multiplier.

## R02 candidate packaging branch

R02 uses the drawing-informed rectangular fan bounding envelope in a hypothetical upright installation. The previous 600 mm fan allowance becomes 825 mm, so preserving its 200 mm outlet allowance increases study height from 1,990 to 2,215 mm. R01 and R00 are preserved. This is an option branch, not selection of the fan or final tower height.

Files: `cad/packaging/AQI_Cylindrical_Packaging_R02.FCStd`, corresponding `NOT_FOR_FABRICATION.step`, `PACKAGING_R02_AUDIT.json`, and `cad/parametric/cylindrical_packaging_r02.json`. The geometric checks still omit actual mounts, transitions, guards and service equipment.

Open R02 and run `scripts/geometry/view_cylindrical_packaging.FCMacro` for a clean colored view. The macro now respects an active R00/R01/R02 packaging document; with none active it defaults to R01. It changes the view only and does not save.

## Evidence and next information needed

Downloaded official catalogue is archived under `data/fans/sources/`; SHA256 and page references are in `data/fans/sp_td2000_315_silent_ecowatt_screening.json`. Source-page preview images are for internal reference, not original project drawings. Generated calculations/CSV/vector plot are under `results/fan_selection/`. Five calculation tests cover interpolation bounds, balance, load trend, chart sensitivity order and non-double-counted hardware.

Next: obtain numeric duty confirmation and exact installation CAD for an India-supported fan; select guards/transitions and replace loss allowances; obtain clean/loaded filter curves; confirm minimum acceptable flow and noise with college mentor; compare quotations and replacement costs. Only then update the selected BOM and detailed electrical circuit. No supplier contacted, component selected or purchase made.

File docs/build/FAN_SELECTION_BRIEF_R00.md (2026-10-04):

# Fan selection brief R00 — ready for quotation review, not ordering

3 October 2026. Prepared by the assistant. NOT SENT. No selected fan or approved performance requirement.

## The decision in plain language

A fan must push air through the filters, not just move air in an empty duct. As filters collect dust, airflow falls unless the fan has enough pressure capability. Buying on the largest free-air number can leave us with a tower that looks complete but delivers too little filtered air.

**RECOMMENDATION:** obtain a documented higher-pressure fan proposal and a matching lower-loss alternative. Compare the complete guarded, sealed fan/filter core before committing to either. Do not force a particular fan into the cylindrical shell; adapt packaging after selection. No outdoor coverage radius is specified by this brief.

## What we know and what we do not

- FACT / user direction: indoor first trial, outdoor final goal; funded commercial review/fabrication/testing, no college lab assumed.
- DETECTED: the historical KVO model identity remains ambiguous; the S&P TD-2000/315 SILENT ECOWATT is an unselected comparison candidate with an archived OEM catalogue and visually digitized curve.
- ASSUMPTION: the study flow is 1,200–1,300 m3/h. The 1,400 point below is a comparison extension, not a raised requirement. Air density is 1.2 kg/m3.
- ASSUMPTION: filter pressure scales linearly from historical partial CFD; hardware losses follow the existing M04 coefficient scenarios. These are not measured bounds or supplier-approved dirty-filter limits.
- UNKNOWN: actual room volume, accepted minimum flow/noise, exact filter curves and terminal resistance, installed fan effects, exact purchasable fan, current prices and lead times.

## Calculated comparison at the same airflow

The table uses [M04 pressure accounting](AIRPATH_AND_PRESSURE_BASIS.md): ambient intake/free discharge, equal effective fan-outlet and terminal areas, so the terminal velocity term cancels in the static-duty comparison. Actual areas and OEM test installation remain unverified. Low/high columns are two input scenarios, NOT uncertainty limits. Coefficients outside them are possible.

| Study flow m3/h | Clean static-duty scenarios Pa | Loaded static-duty scenarios Pa | Historical KVO chart Pa | S&P digitized chart Pa |
|---:|---:|---:|---:|---:|
| 1,200 | 149–223 | 298–372 | 205 | 290 |
| 1,300 | 163–250 | 326–413 | 137 | 230 |
| 1,400 | 179–279 | 353–454 | 69 | 175 |

Clean assumption: HEPA 111.2 Pa plus prefilter 25 Pa at 1,332 m3/h. Loaded assumption: twice that HEPA resistance plus prefilter 80 Pa at the same reference flow. These are sensitivity inputs, not maintenance settings. No carbon, rain louvre, silencer, bend or narrow jet nozzle is included. Add any such parts before selection.

At 1,300 m3/h the S&P estimate is about 96–183 Pa below the loaded scenarios. Its +/-25 Pa chart-reading sensitivity is not total uncertainty. The historical KVO estimate is about 189–276 Pa below them. Neither is confirmed adequate for this assumed loaded duty. This does not prove either fan is unusable at another accepted flow or in a redesigned lower-resistance system.

A clean-case pass is not a loaded-case pass. Increasing speed without an OEM curve/limit is not an approved remedy. Final comparison needs curves at actual speeds, current/power, stable operation, sound and installation acceptance.

## Copyable supplier request — prepared, not sent

We are developing a particulate-only air-cleaning tower for a first indoor trial, using a coarse prefilter and sealed HEPA cassette. Final outdoor development is separate. Please propose exact India-supported fan/controller packages for comparison; this is a quotation and engineering-information request, not an order.

Our provisional main study flow is 1,300 m3/h. Under explicitly unmeasured assumptions, static duty is approximately 163–250 Pa clean and 326–413 Pa loaded. Please report a selection at **1,300 m3/h / 250 Pa** and **1,300 m3/h / 420 Pa**, with the latter only a rounded screening benchmark, not an approved requirement or safety margin. Include the same unit's speed settings/power/sound at both points, or explain why different units/layouts are needed. Also show coverage near 1,200 m3/h / 375 Pa. We will replace these assumptions with selected-filter/installation data before procurement.

Please provide:

1. Exact fan article/revision, motor type, compatible controller/accessories and matching numeric speed-dependent curves. State static versus total pressure, density, test arrangement and stable operating region. Do not send only free-air flow or motor watts.
2. Electrical input/current at each requested point, permitted maximums, inrush/leakage data as applicable, supply requirements, wiring manual, motor-protection reset and disconnected-speed-command behavior. Restart prevention is a project requirement; do not assume internal auto-reset is acceptable.
3. Dimensioned drawing/STEP, true inlet/outlet flow areas, spigot tolerances, mounting holes, mass, allowed orientation, cable-box/access clearances and approved vibration isolation.
4. Acceptance or correction for our compact square-to-round inlet, short neck, guards and short outlet. Current layout is an unapproved fit study. Advise a less compact arrangement if needed; identify every extra adapter/guard/accessory and loss included in your selection.
5. Sound data with method and operating point, including inlet/outlet/casing contributions where available. Catalogue sound pressure under different room/distance conditions is not a promised assembled-tower result.
6. Itemized India quote including controller, mounts, adapters, tax/freight, warranty, lead time, service and replacement availability. All currently UNKNOWN.

Please return source/manual revision and selection report. No substitute article should inherit another model's curve or wiring. We will obtain qualified mechanical/electrical review and inspect/test the actual assembled unit before use.

## How a response is evaluated

Use the [response sheet](FAN_SUPPLIER_RESPONSE_R00.csv). Missing evidence stays UNKNOWN, not PASS. Do not average critical failures into an overall score.

1. Confirm accepted flow and OEM filter maintenance conditions with the project team/reviewer.
2. Rebuild the complete clean/loaded loss budget on the supplier's pressure basis; avoid double-counted exit energy. Recalculate for their actual areas and installation.
3. Check both operation points and the intervening operating range, OEM limits and installed effects. Keep power and sound separate from airflow evidence.
4. Check exact drawing, orientation, service access, support loads and electrical/control compatibility.
5. Compare delivered cost and recurring parts/service only after technical suitability; no prices fabricated here.
6. Record a justified selection with reviewer scope, then update CAD/BOM and rated electrical E01–E06. Current sheet closes no build gate.

Possible decision outcomes: SELECTABLE_AFTER_REVIEW, REVISE_LAYOUT_OR_DUTY, INCOMPLETE_EVIDENCE, or REJECT_FOR_THIS_DUTY. None is assigned to an actual supplier response yet.

## Reproduce the table without changing prior results

From the project root:

```powershell
python -c "import sys; sys.path.insert(0,'scripts/analysis'); from airpath_loss_screen import screen; from fan_duty_screen import FANS,interp; print([(q,screen(q)['same_area_terminal_vs_fan_outlet_static_duty_clean_Pa'],screen(q)['same_area_terminal_vs_fan_outlet_static_duty_loaded_Pa'],{n:round(interp(c,q),2) for n,c in FANS.items()}) for q in (1200,1300,1400)])"
python -m unittest discover -s scripts/analysis -p 'fan_duty_screen.py'
python -m unittest discover -s scripts/analysis -p 'airpath_loss_screen.py'
```

Ten existing arithmetic/screening tests passed on 3 October 2026. No new CFD, physical measurements, power prediction or purchase selection follows from those tests.

## Sources and evidence

- [AMCA fan-curve explanation](https://www.amca.org/educate/articles-and-technical-papers/amca-inmotion-articles/straightening-out-fan-curves.html), checked 3 October 2026: duty comparison must match pressure basis, test arrangement and operating point. It does not certify this tower.
- [Official S&P catalogue](https://statics.solerpalau.com/media/import/documentation/EN_TD-SILENT-ECOWATT.pdf), archived/reviewed 2 October; new web fetch failed on 3 October. Local source/hash and chart-reading limitations remain in `data/fans/sp_td2000_315_silent_ecowatt_screening.json`. Current stock/revision not verified.
- Local calculations: `scripts/analysis/airpath_loss_screen.py`, `scripts/analysis/fan_duty_screen.py`; previous [fan decision](FAN_DUTY_DECISION.md). Historical HEPA input is digital, partial/nonconverged evidence, not a physical new-cassette curve.

Next useful external input is one complete OEM selection response plus filter pressure curves—not another guessed fan envelope. No supplier has been contacted through this brief.

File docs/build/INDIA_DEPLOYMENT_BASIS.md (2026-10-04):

# India deployment basis — heat, public access and size

3 October 2026. Applies to D01 and the eventual outdoor tower. **Engineering recommendations, not construction release.** User has explicitly requested Indian temperature suitability, robustness against public misuse, size and location to be considered. Physical prototypes: 0.

## Decision in plain language

**D01 is an indoor learning prototype, not an outdoor street product.** Retain its assembly to test real fan/filter performance and sealing. Do not place it outdoors or leave it accessible to the public. Putting a metal cover around it would not qualify its fans, filters, controls or structure for heat, rain or tampering.

Recommended first host: a supervised room in a college or NGO building, with an identified operator, safe power and permission to test. No lab is assumed. After a separately qualified outdoor assembly exists, the first outdoor pilot should be an operator-managed campus/NGO courtyard or sheltered waiting area with staff oversight, maintenance access and approved anchoring. A shelter does not remove wind-driven rain or public-access requirements. Do not start at an unattended roadside, traffic island, exposed bus stop or flood-prone location.

Intended eventual application: investigate local particle reduction near a defined occupied waiting/seating area. This is not a city-wide pollution solution or a proven clean-air bubble. Record wind and background pollution and compare conditions at occupied locations; do not infer radius/spacing from fan flow. Avoid claims of gas removal or protection from vehicle exhaust as a whole.

## Heat: present component fails the blanket outdoor assumption

**VERIFIED OEM FACT:** ARCTIC lists P14 Max operating ambient as 0–40 C. **VERIFIED CLIMATE EVIDENCE:** IMD's Telangana extremes table updated to May2025 lists Hyderabad at45.5 C. This is an observed extreme, not a complete design climate or a limit for all India. Even without solar heating it exceeds the fan limit by5.5 C. Actual conditions for Pune/Mumbai and the chosen site remain to be established.

**RECOMMENDATION for D01 tests:** dry indoor operation, no direct sunlight; use35 C at the fan inlet as a provisional screening ceiling, leaving5 C to this fan's maximum. Measure fan-inlet and supply/controller enclosure temperatures at full load and during reduced-airflow conditions using an agreed safe procedure. Follow the lowest actual component rating. This is NOT an implemented cutoff or permission to energize: supply/controller thermal limits, startup and existing restart-protection gates remain open. Do not operate deliberately outside OEM limits.

**OUTDOOR DESIGN REQUIREMENT:** set site ambient, solar exposure, enclosure temperature rise, humidity/condensation and storage limits before final component selection. As an initial hot-site sourcing screen only, investigate components for50 C external ambient plus the verified local enclosure rise; a hypothetical10 C rise would require suitability at60 C at the component. Neither number is an approved India-wide design condition. Temperature-rated industrial fans may be needed. A light-coloured shaded shell and ventilated air path are candidate measures, not proof of adequate cooling. Do not seal electronics into an unverified hot box.

## What the public version needs

| Exposure | Design direction to carry into the assembly | Evidence needed before public deployment |
|---|---|---|
| Rain, wet cleaning and flooding | Downward-facing/weather-baffled openings, separated drainage, raised dry electrical compartment; no water route to filter or electrics | Installed ingress assessment/test, chosen site flood/drainage review; no IP claim yet |
| Dust and insects | Accessible replaceable screen/prefilter only after pressure budget supports it; sealed filter edges; no uncharacterized restrictive mesh | Supplier pressure curves, loading checks and maintenance interval from actual conditions |
| Kicking, leaning and thrown objects | Load-bearing metal frame, replaceable tough panels, protected filter faces, recessed controls and rounded edges | Selected grade/thickness, joints, deformation and reach checks; impact test plan for applicable classification |
| Theft and opening panels | Lockable service door, captive/tamper-resistant fasteners, concealed anchors and cables, no exposed removable filter or fan fixings | Access/retention review and service procedure; tamper-resistant is not vandal-proof |
| Tipping and climbing | Engineered anchoring to an approved substrate; no easy footholds; not a seat/table; avoid movable castors in public use | Full mass/CG, support geometry, wind/misuse loads, substrate and anchor verification |
| Corrosion, sunlight and humid/coastal exposure | Site-appropriate coated metal or corrosion-resistant alloy; protected cut edges, compatible fasteners and UV-suitable exterior materials | Actual coating/material specification, joint compatibility and exposure tests; material not selected yet |
| Fans, sharp edges and electrics | Independently retained guards, protected wiring, tool-controlled service access and deliberate restart after interruption | Mechanical reach/deflection and qualified electrical/commissioning review; no Arduino-only safety function |

IP refers to ingress protection and IK to mechanical-impact classification. They are different. A rated purchased box does not rate the whole tower after holes, glands, vents and doors are added. Use IEC60529 and IEC62262 as classification references while the reviewer establishes the applicable product standards and Indian requirements. No IP/IK certification or exact target rating is claimed here. Do not perform improvised impact/water tests on energized equipment.

The current plywood panels, exposed filter faces, projecting studs, external control reservation and shared guard bolts are **not public-product details**. A public version needs engineered replacements, not just paint or cosmetic sheet wrapping. Guards must remain secure during ordinary access; the current shared-bolt arrangement does not establish that.

## Size and airflow consequences — actual calculations

**DETECTED design envelope:** D01 is roughly590 W x490 D x631 H mm including the current control/stud reservations, not merely its550 x360 cabinet. It is a floor-sized demonstrator, not a pocket-size model. Service clearances and protected cables add to occupied space; these are not included in the envelope.

A circular sleeve enclosing that rectangular envelope requires about767 mm internal diameter before clearance; with an **assumed**25 mm radial allowance it is about817 mm ID. This is a conservative rectangle-fit screen, not a selected cylinder dimension. No wall, hood, airflow/service clearance or weather protection is included. Therefore do not promise a slender Dyson-like cylinder by wrapping D01: a slender version would need different internal packaging and possibly different filters. Keep R01 unchanged until real parts establish the next packaging decision. Final outdoor height/diameter remain UNKNOWN.

The new script also adds illustrative weather/guard loss of0/5/10/20 Pa at300 m3/h to the existing middle-filter scenario. Loss scales with flow squared; these are **not measured hood coefficients**. Read `reports/prototype_d01/component_validation/deployment_screen.json` for the solved operating points. This demonstrates why rain baffles, anti-vandal screens and extra filters cannot be added without recalculating fan duty.

For stability, illustrative10/20/30 kg units with assumed150 mm CG-to-support-edge distance and a push at631 mm height would start static overturning at approximately23/47/70 N. These are NOT actual D01 capacities, rated test loads or acceptable thresholds. Real mass/CG, support polygon, sliding, dynamic impact and anchors are unknown. The calculation shows why adding weight or a wide cosmetic shell is not a substitute for proper anchoring.

## Fast route, without restarting the project

1. Keep building toward the existing D01 indoor particle test. Exact filter resistance/dimensions, guards/joints/seals and restart protection still need closure; no decorative cylinder is on the critical path.
2. Use measured airflow, leakage, temperature and power to select the outdoor fan/filter core. Do not scale from partial historical CFD or unmeasured D01 predictions.
3. Apply the public-use requirements above to one integrated outdoor assembly. Choose its site before freezing anchors, weather design, noise and pedestrian/service clearances. A named host/operator and maintenance responsibility are prerequisites.

Next external decision eventually needed: **the actual host location and indoor test room**, not necessarily a city today. College/NGO funding does not imply site approval or maintenance staffing. No purchase, installation, supplier contact or public deployment is authorized by this document.

## Sources and reproducibility

Accessed2026-10-03:

- [ARCTIC P14 Max black product page](https://www.arctic.de/en/P14-Max-Black/ACFAN00287A) — operating ambient0–40 C. Existing archived specification PDF corroborates the thermal limit; earlier SKU/curve discrepancies remain documented separately.
- [IMD Telangana extremes, updated May2025](https://mausam.imd.gov.in/hyderabad/mcdata/tlngextwx.pdf) — Hyderabad45.5 C. Not a site design-weather study.
- [IEC60529 official scope](https://webstore.iec.ch/en/publication/2447) — ingress classification.
- [IEC62262 consolidated official scope](https://webstore.iec.ch/en/publication/71109) — external mechanical-impact classification. Public scopes reviewed; no purchased standard or claim of full compliance.

Run `scripts/analysis/d01_deployment_screen.py` using existing Python. Five arithmetic/regression checks; no new simulation, physical result or material strength certification. The aqi-build-review skill required the indoor/outdoor boundary and added-loss consequences to be explicit. Historical models remain unchanged.

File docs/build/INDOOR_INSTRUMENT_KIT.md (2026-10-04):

# Practical equipment for the first indoor test

3 October 2026. RECOMMENDATION / OEM REFERENCE CHECK — NOT AN ORDER OR WIRING RELEASE.

## Simple decision

USER UPDATE: no college lab is available; college/NGO provide funding only. Follow [the no-lab route](NO_LAB_BUILD_ROUTE.md): buy monitoring instruments, rent specialist equipment or hire an equipped test service. Start with the existing laptop; no custom PCB, wireless dashboard or extra computer is necessary for the current offline recorder.

Use [the revised equipment request sheet](INDOOR_INSTRUMENT_REQUEST_NO_LAB.csv) to record actual models, calibration, availability and interfaces. All availability/prices remain UNKNOWN. Quantities below are proposed test arrangements, not approved purchases. The older college-based CSV could not be overwritten and is retained as superseded history; use this new revision.

| Measurement | Proposed first arrangement | Buy/rent/service route | What must be confirmed |
|---|---|---|---|
| Room PM2.5 trend | Two matched logging monitors, at two recorded room positions | Buy complete supported instruments/kits; see no-lab route | Export format, co-location checks, usable floor, uncertainty and humidity response |
| Prefilter and HEPA pressure loss | Two simultaneous signed differential-pressure channels | Buy calibrated manometer/logger or rent for commissioning; digital modules optional | Clean/loaded/fault range, reference check, tubing and tap installation |
| Actual whole-tower airflow | Calibrated capture hood or reviewed duct-traverse setup | Hire equipped service or rent with experienced operator | Outlet coverage, range, backpressure correction, geometry and uncertainty |
| Electrical input | Suitable power analyzer operated under the approved electrical procedure | Hire service or rent | Actual supply/load compatibility, safe connection and calibration |
| Sound | Calibrated sound instrument with its check equipment | Hire service or rent | Method, location, background noise and calibration |
| Temperature/humidity | Logging instrument near particle sampling locations | Buy appropriate logger | Recorded locations, calibration and response time |
| Room dimensions | Tape/laser distance instrument plus room/ventilation survey | Buy/use existing | Actual usable room geometry, connected spaces and opening state |
| Data capture | Existing laptop and original instrument exports | Use existing | Clock synchronization, USB/export support and run metadata |

Two room monitors help detect spatial differences; they are not automatically an upstream/downstream filter-efficiency pair. These quantities do not constitute reference-grade particle testing or whole-device HEPA certification.

## Checked candidate: SPS30 particle monitoring

**OEM FACT:** [Sensirion SPS30 data sheet](https://sensirion.com/media/documents/8600FF88/64A3B8D6/Sensirion_PM_Sensors_Datasheet_SPS30.pdf), version 2.0–D1, June 2023, pages 2–3 and 16, retrieved 3 October 2026: mass range 0–1,000 ug/m3. PM2.5 precision below 100 ug/m3 is +/-[5 ug/m3 + 5% of measured value]; above that, +/-10%. The sheet describes this precision as device-to-device variation, not the complete uncertainty of our experiment. Supply is 4.5–5.5 V. UART/I2C are available; I2C address is 0x69. OEM cautions about cable interference and recommends UART where possible.

**RECOMMENDATION:** evaluate two matched ready-to-log instruments before buying bare modules. If SPS30 is chosen, obtain the exact bridge/board/cable documentation. Use co-location and comparison against suitable reference equipment where available. Do not infer a detection limit from the precision formula, or claim a small difference between sensors is real cleaning. The usable floor for decay analysis is still UNKNOWN.

## Checked candidate: filter-pressure monitoring

**OEM FACT:** [Sensirion SDP8xx digital data sheet](https://sensirion.com/file/datasheet_sdp800-d/), version 1.1, April 2019, pages 2–3 and 6, retrieved 3 October 2026: SDP810-500Pa uses tube connections and measures -500 to +500 Pa; I2C address 0x25. SDP811-500Pa uses 0x26. Supply is 2.7–5.5 V; media compatibility is non-condensing. Published zero-point accuracy is 0.1 Pa plus span accuracy 3% of reading under stated test conditions. These are not our installed tubing/measurement uncertainty.

**RECOMMENDATION:** keep this family as a candidate, not a selected range. Confirm maximum differential across each filter at the actual loaded/fault conditions first. Overpressure survivability is not a valid measurement range. Use a bought/rented calibrated instrument with adequate range for commissioning. Confirm sign, zero/reference check, tap placement and contamination/condensation protection without introducing an uncharacterized restriction. Do not interpret pressure directly as airflow without a calibrated relationship.

## Connection issue found before ordering

**INFERENCE from the documented addresses:** two SPS30 units share 0x69; two SDP810 units share 0x25. Identical-address units cannot be separately addressed on one unswitched I2C bus.

Review one of these arrangements before selecting cables/boards:

- Separate supported USB/UART acquisition paths for the room monitors, with short local sensor connections. Actual bridge compatibility remains UNKNOWN.
- Separate controller buses or a reviewed I2C multiplexer for duplicate addresses.
- For pressure only, the documented SDP810/SDP811 address pair is an option if both ranges and exact supplied variants are acceptable.

No pin assignments, pull-up network, power adapter, controller SKU or cable-length release is given here. An interface name alone does not establish voltage compatibility. No live acquisition driver exists yet, and none of these paths controls the mains fan or its safety functions.

## Airflow instrument reference—not a purchase recommendation

**OEM FACT:** [TSI AccuBalance 8380 specification](https://tsi.com/getmedia/b057b3f8-c6c6-425f-ac69-c62a0dfb907e/8715-8380_AccuBalance_US_5001431?ext=.pdf), page 3, reviewed 3 October 2026: capture-hood range 42–4,250 m3/h. Its published accuracy above 85 m3/h is +/-3% of reading +/-12 m3/h. This is a range reference; college possession, price and availability are UNKNOWN.

The exploratory 1,200–1,300 m3/h target lies inside that catalogue range, but this does NOT establish suitability for our outlet. Operator must assess fit, discharge pattern and instrument-induced backpressure. Alternatively obtain a reviewed traverse method with suitable straight measurement geometry. Do not use one centre-point airspeed reading times gross grille area as validated whole-device flow. The earlier short outlet study is not an approved measurement section.

## Where the instruments go

```text
Air path (not to scale):
intake -> P0 -> prefilter -> P1 -> HEPA -> P2 -> fan -> outlet flow measurement
            |                |             |
            + DP_PREF high   + DP_PREF low  + DP_HEPA low
                             + DP_HEPA high

Room PM A and room PM B: independent recorded positions outside the tower.
Temperature/humidity: recorded room position(s), not assumed sensor-chip temperature.
Power analyzer: electrical reviewer-approved measurement arrangement only.
Laptop: receives data; NO connection to fan safety functions.
```

P0/P1/P2 are conceptual static-tap locations, not drilled-hole dimensions. Choose actual positions/geometry with the test mentor to avoid local velocity effects. P1 can feed separate reference tubes to the two instruments only through reviewed airtight connections. Record positive convention as upstream minus downstream and check it before measurements. A physical tubing/installation drawing is still required.

## Exact next action without a college lab

Obtain supplier/service quotes using the equipment sheet: model, range, calibration/reference record, availability date and export method. Include competent airflow measurement and qualified mechanical/electrical review as paid scopes where needed. ENTC review is optional and does not replace assistant preparation. Do not buy a Raspberry Pi or sensors simply to fill a blank BOM row. Once instruments are confirmed, we can write the matching export/live adapter and complete the measurement installation drawing.

No request sent, equipment obtained, parts ordered or physical data collected. Existing [test gates](BUILD_AND_TEST.md), [recorder](MEASUREMENT_RECORDING.md) and [exploratory analysis](INDOOR_DECAY_ANALYSIS.md) remain the workflow. Outdoor sensing/weather protection is a separate later design.

## Source audit

Archived under `data/monitoring/sources/`; downloaded 3 October 2026. Sensirion specification table pages were rendered and visually checked. Keep OEM copyright; review redistribution permission before public publication.

| PDF | SHA256 |
|---|---|
| SPS30_review_2026-10-03.pdf | 93573ca35f7e239b947b78b31568812972dc6ca49fe558837e2efc3d37b5421a |
| SDP8xx_digital_review_2026-10-03.pdf | dbcbad9c96a414903676b160715a082126f0a5f6fe37441114965aebebbf9835 |
| TSI_8380_review_2026-10-03.pdf | f478a890a0a5ce98990d18f7902b28bbee03df591c49074619c5994cec8f04a5 |

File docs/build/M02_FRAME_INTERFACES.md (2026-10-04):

# M02 frame routing and mounting interfaces

2 October 2026. SPATIAL STUDY ONLY — NOT FOR FABRICATION.

## What we now have

Follow-on option: [M02/M03 segmented capped-post branch](M02_M03_SEGMENTED_INTERFACE.md) removes the eight nominal clashes without cutting the plates, but changes load transfer. This document records the earlier continuous-post study; it is preserved for comparison.

A separate 3D frame-routing study shows where four upright supports and four levels of connecting rails could fit. It does not alter R02 or the M04 air-path CAD. Read the [visual layout](M02_FRAME_LAYOUT.html) alongside the [weight/stability review](M02_WEIGHT_STABILITY.md).

**DETECTED:** twenty valid hollow-profile solids, native FreeCAD reopen and STEP reimport passed. Thirteen existing reference objects were checked for positive-volume interference. No nominal interference was found with the shell, service-door pieces, filter envelopes, gasket/retainer envelopes, fan bounding box or M04 air-path study. No route-to-route positive-volume clashes occurred. The assumed lifted HEPA sweep also cleared the frame.

**ASSUMPTIONS:** upright centres x = +/-350 mm, y = +/-200 mm; start/end z = 150/2,050 mm. A 35 mm square profile with 3 mm wall was used ONLY to give the routing a visible volume. Neither those dimensions nor the material is selected. Rail top levels are 185, 445, 640 and 1,190 mm. Frame envelope is 735 x 435 mm; nominal clearance from the 593 mm filter side to the posts is 36 mm. Real assembly/tool/handling tolerances remain unassessed.

The assumed steel routes alone weigh **47.75 kg**, excluding base, feet, joints, gussets and actual mounts. This does not solve the weight problem merely by adding an independent frame. Compare revised section sizes/topologies and lighter cladding with the reviewer; do not purchase this profile from the study.

## Important fit failure — not hidden

**DETECTED:** each of the four continuous posts intersects each of the two existing filter bulkhead plates: eight clashes, each 1,920 mm3 of solid overlap. The routing model therefore CANNOT be assembled with the current unmodified plates. Those plates remain unchanged.

Do not just drill square clearance holes and call it finished. The HEPA plate separates dirty air from clean air. Gaps around posts could bypass the HEPA. A hollow post can also communicate between dirty and clean zones through open ends or unsealed joints, even if its outside perimeter looks sealed. None of these interfaces is modeled as leak-tight or tested.

**RECOMMENDATION:** compare these routes before freezing M02/M03 together:

| Route | Advantage to investigate | Unresolved issue |
|---|---|---|
| Continuous internal posts | Direct support path and compact casing | Plate penetrations AND hollow-post air paths need a reviewed sealing solution; intake/free-area effects remain unmeasured |
| External frame supporting sealed enclosure | Could keep primary members outside the pressure boundary | Larger footprint, appearance, door access and mounting arrangement change; not modeled here |
| Segmented supports joined at a sealed structural boundary | Could avoid an open tube across the HEPA boundary | Boundary must transfer structural loads and retain flatness/sealing; connection design not complete |

Camfil's [GlidePack housing information](https://www.camfil.com/en-ca/products/housings-frames--louvers/ducted-housing/glidepack) distinguishes filter-to-track sealing from housing pressure-boundary integrity in its commercial assembly (reviewed 2 October 2026). It is a useful interface example, not certification of our cassette, posts or frame. The exact filter's installation instructions remain necessary.

## Frame/base and mounting interface register

| ID | What connects | Geometry currently available | Before this can be released |
|---|---|---|---|
| M02-01 | Uprights to base | Four assumed routes; base only a reserved volume in R02 | Choose actual base/feet/contact polygon, joint detail, floor/handling loads and corrosion arrangement |
| M02-02 | Prefilter tray to frame | Rail top z445; old plate intersects posts | Actual filter mass/frame/ledge, tray clearance, seals, loaded differential and removal method |
| M02-03 | HEPA seat/retainer to frame | Rail top z640; illustrative R01 seat and gasket | Resolve penetrations, gasket preload/flatness, filter orientation, supports and bypass integrity |
| M02-04 | Fan to frame | Rail top z1190; candidate bounding envelope | OEM mounting holes/feet, permitted upright orientation, load/CG, vibration isolation and removal access |
| M02-05 | Casing/doors to frame | Casing and door volumes clear nominally | Attachments, seams, latches/hinges, corrosion and filter-service access; no live/spinning-part exposure |
| M02-06 | Outlet and guards to frame | Separate M04 study clears routes | Real fan port axes/flanges, adapter attachments, guard geometry/losses and service support |
| M02-07 | Electrical enclosure to frame | Not included in this routing fit check | Locate actual enclosure, confirm access/cooling/cables and qualified bonding/protection design |

Do not bolt through a fan casing, clamp a filter media pack, or use the airflow adapter as the fan's support without component-specific approval. The current rails do not constitute a fan cradle. Base/feet, lifting points, wheels, fasteners and structural load ratings are still UNKNOWN.

## What the checks do NOT establish

No member stress/deflection/buckling analysis, vibration assessment, weld/bolt/anchor sizing, complete mass/CG, actual tipping/sliding approval, seal integrity, guard accessibility or outdoor weather performance. Touching surfaces are not proven joints. A geometric service sweep is not a safe lifting/removal procedure. Exact OEM fan service envelope and true filter frame/gasket are unavailable. Positive-volume clearance does not establish acceptable airflow obstruction or installation effect.

## Files and reproduction

- `cad/parametric/frame_route_m02.json`: explicit routing assumptions.
- `scripts/geometry/create_frame_route_study.py`: standalone study generator; preserves earlier CAD.
- `cad/packaging/AQI_M02_Frame_Routing_STUDY.FCStd`: editable shape snapshots, not spreadsheet-parametric members. Edit the JSON and regenerate for dimensional changes.
- `cad/packaging/AQI_M02_Frame_Routing_NOT_FOR_FABRICATION.step`: exchange geometry.
- `cad/packaging/M02_FRAME_ROUTING_AUDIT.json`: valid solids, reference clashes, assumed removal sweep, mass and clearances.

```powershell
& 'D:\Applications\FreeCAD 1.1.3\bin\python.exe' scripts/geometry/create_frame_route_study.py
```

Regeneration replaces these derived study outputs; preserve manual edits before running it. It does not replace R02 or M04 files.

**Next release gate:** obtain OEM filter/fan mounting information, select the frame-to-sealed-cassette architecture with the mechanical reviewer, then produce integrated assembly CAD and dimensioned frame/base/connection drawings. Resolve all eight plate clashes and every potential HEPA bypass path before fabrication. No parts ordered or supplier messages sent.

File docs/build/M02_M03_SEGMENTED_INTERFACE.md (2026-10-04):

# M02/M03 — segmented support / sealed-boundary fit branch

2 October 2026. OPTION STUDY — NOT APPROVED FOR FABRICATION OR OPERATION.

## In simple language

Instead of running one hollow post through the filter plates, this branch stops the post at each plate and starts another closed-ended section above it. The plates have no new post holes. This removes the earlier solid overlaps and avoids modeling an open post bore straight through the HEPA boundary.

The plates now become part of the load path. That is a trade-off, not a completed structural solution. Their thickness, stiffness and connections are not approved. Keep the earlier continuous-frame study for comparison; this branch is not a final architecture selection.

See the [interface illustration](M02_M03_SEGMENTED_INTERFACE.html).

## Evidence from the executed CAD checks

**DETECTED:**

- 28 valid frame-route solids: twelve capped upright segments plus sixteen horizontal rails.
- Zero positive-volume clashes with the thirteen checked R02/M04 reference objects; zero route-to-route clashes.
- Zero frame clashes with the previous assumed lifted HEPA service sweep. This is not an operator handling assessment.
- Sixteen calculated post-cap/plate face contacts, each 1,225 mm2, at z445, 450, 640 and 645 mm. Contact area is geometry, not joint strength.
- Separate frame FreeCAD/STEP and combined 41-solid snapshot FreeCAD/STEP reopened/reimported successfully.
- SHA256 checks confirm the R02 casing/cassette CAD and M04 air-path CAD were not changed.

**ASSUMPTIONS:** profile outer size 35 mm, wall/end closure 3 mm; same post x/y centres and rail levels as the previous study. Upright intervals are z150–445, z450–640 and z645–2,050 mm. The two existing plates occupy z445–450 and z640–645 mm. These are study coordinates, not toleranced manufacture dimensions. Nominal zero-gap face contact is not a practical joint or assembly clearance specification.

Using assumed steel density 7,850 kg/m3, the segmented routes weigh **48.10 kg**, compared with 47.75 kg for the earlier continuous routes. This is a replacement frame option, not an additional frame to add to it. It excludes base, feet, joints, gussets, mounting hardware and coating. Weight optimization remains unfinished.

**UNKNOWN:** assembled leakage, actual weld quality, plate/load capacity, approved material/profile, fan cradle, real OEM installation fit, total mass/CG and base stability.

## What is resolved, and what is not

| Issue | This branch does | Still required |
|---|---|---|
| Eight post/plate CAD clashes | Stops each post at existing plate faces; no overlap in tested geometry | Dimensioned joints, stack tolerance and manufacturing review |
| Open vertical bore crossing HEPA plate | Models ideal solid end closures on every upright segment and leaves plate unperforated at posts | Review real welded/closed joint details and leak-test the assembled boundary |
| Filter removal | Preserves assumed filter-envelope sweep clearance | Actual filter/retainer handling, tray/latches and OEM tolerances |
| Structural load path | Routes upper loads through post caps, plates and lower segments | Bearing, bending, deflection/flatness, buckling and joint-load calculations |
| Fan support | Keeps the candidate envelope and lower rail route | Actual mounting feet/holes, allowed orientation, vibration isolation and cradle |

Horizontal rails still have modeled open ends; there is no declared airtight welded frame assembly. The caps represent ideal geometry, not a weld/cap fabrication detail. No fastener holes have been drawn through the plates. Future holes, threads, seams, pressure taps and cable passages must be reviewed as potential leaks; added cuts require repeat fit and seal checks.

The HEPA seat/gasket/retainer are still illustrative R01 geometry, not supplier-approved hardware. The bulkhead-to-casing perimeter joint and service-door seams are also unvalidated. Removing one potential post bypass does not establish whole-device HEPA performance. The prior [Camfil commercial housing example](https://www.camfil.com/en-ca/products/housings-frames--louvers/ducted-housing/glidepack) distinguishes filter-to-track sealing from housing integrity; it was reviewed in the preceding step on 2 October 2026, but the current refetch timed out. It is not approval of this branch.

## Load-transfer review before committing to this route

Follow-on [plate load/connection sensitivity](M02_PLATE_LOAD_REVIEW.md) now calculates partial above-plane masses and illustrative reactions. It does not approve the plates. Resting contact cannot establish shear/uplift restraint; compare a separately sealed housing with a continuous surrounding frame before freezing this option.

The reviewer must assess vertical loads, fan vibration, lateral loads and uplift/retention separately. Face-to-face contact does not restrain tension, sliding or lateral motion. No plate penetration or bolt size is authorized here.

1. Obtain exact fan/filter masses, CG/mounting drawings and permitted orientation.
2. Evaluate load transfer through each plate, including local bearing, plate bending, seal-plane deflection and the interruptions caused by the filter opening.
3. Decide whether reviewed segmented connections can retain alignment/sealing, or an external frame with a separate sealed housing is preferable.
4. Design base, actual floor contacts, joints and handling arrangements; calculate full mass/CG and service-state tipping/sliding.
5. Complete assembly drawings, structural review and installed leak-test plan before fabrication release.

No plate size, frame section, welding process, mains wiring or anchor is approved by this fit study. An indoor-first build remains the recommendation; outdoor design and cleaning-zone claims need separate evidence.

## Files and repeatability

- `cad/parametric/frame_route_m02_segmented.json`: branch inputs.
- `cad/packaging/AQI_M02_Segmented_Frame_STUDY.FCStd`: standalone frame snapshot.
- `cad/packaging/AQI_M02_Segmented_Frame_NOT_FOR_FABRICATION.step`: frame exchange geometry.
- `cad/packaging/AQI_M02_M03_Integrated_Fit_STUDY.FCStd`: casing/doors, filter/gasket/retainer envelopes, fan bounding box, M04 and frame snapshots together.
- `cad/packaging/AQI_M02_M03_Integrated_NOT_FOR_FABRICATION.step`: combined exchange geometry.
- `cad/packaging/M02_SEGMENTED_FRAME_AUDIT.json`: fit/contact/mass/roundtrip evidence.

The combined snapshot excludes base/electrical allowances, guards, exact OEM hardware and actual joint details. It is not a complete manufacturing assembly. Its shape snapshots are not spreadsheet-parametric; change JSON and regenerate. Save manual edits elsewhere first: regeneration replaces only the derived branch outputs. Default generator operation still creates the earlier continuous routing study.

```powershell
& 'D:\Applications\FreeCAD 1.1.3\bin\python.exe' scripts/geometry/create_frame_route_study.py --config cad/parametric/frame_route_m02_segmented.json
python -m unittest discover -s scripts/analysis -p 'test_segmented_frame_audit.py'
```

No supplier messages, purchases, CFD runs or physical tests were performed.

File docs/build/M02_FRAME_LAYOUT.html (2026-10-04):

AQI TOWER · MECHANICAL STUDY · 02 OCT 2026

# A frame that carries the parts

The outer casing is separate from the supports. This sheet shows an assumed route, not metal sizes to order or a safe-to-build drawing.

Eight real CAD clashes found. Four posts cross both filter plates. Holes or open hollow tubes could let dirty air bypass the HEPA. A reviewed support-and-seal interface is required; do not cut holes from this drawing.

What passed: twenty valid route solids; FreeCAD reopen and STEP reimport; nominal clearance from checked component envelopes and the assumed HEPA removal sweep.

Still unknown: approved member sizes, joints, fan mounts, complete weight/centre of gravity, strength, tipping/sliding, installed leakage and outdoor anchoring. The assumed 35 × 35 × 3 mm steel routes add about 47.75 kg before base and hardware.

Illustration simplifies the elevation; dimensions are routing assumptions only. See M02_FRAME_INTERFACES.md and M02_FRAME_ROUTING_AUDIT.json. NOT FOR FABRICATION.

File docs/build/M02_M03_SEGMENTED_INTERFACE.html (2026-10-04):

AQI TOWER · M02 / M03 · OPTION STUDY

# Keep the supports from piercing the filter plate

New branch: split and cap the posts at the existing plate. The CAD overlaps disappear—but the plate must now transfer the loads safely.

New responsibility: the plate and connections must carry the upper structure. Contact faces alone do not hold against sliding or uplift. Strength, weld/cap details, alignment and real leakage still need review and tests.

Detected: 28 valid frame solids; 41 solids in the combined fit snapshot; zero checked positive-volume clashes; assumed filter-removal sweep clear; sixteen nominal cap/plate contacts. FreeCAD reopen and STEP reimport passed.

Assumptions: 35 mm square profile, 3 mm walls/end closures, existing 5 mm plates. Neither member sizes nor materials are approved. Frame routes alone: about 48.10 kg at assumed steel density.

Section exaggerated for clarity, not to scale. Caps are ideal CAD geometry, not approved welding details. Base, actual fan mounts, door seals and installed leakage remain unresolved. NOT FOR FABRICATION.

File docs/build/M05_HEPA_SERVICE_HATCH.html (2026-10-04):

AQI TOWER · M05 · HEPA ACCESS OPTION

# A cover we can remove to service the filter

A separate mounting frame, gasket space and cover replace the earlier flush panel. The latch and handle rectangles reserve locations only.

Not a working latch design. Actual latch/catch hardware, cover support against dropping, mounting joints, seal compression and panel stiffness still need review. No claim of airtightness or safe operation.

Detected: 48 valid CAD solids; no modeled clashes; assumed forward cover, HEPA and retainer removal paths clear. Retainer side margin increases from 1 to 6 mm.

New branch assumptions: 980 mm casing internal diameter and 700 mm outer access width. Original 950 mm model preserved. The prefilter access detail remains preliminary.

Schematic illustration, not to scale or for fabrication. CAD snapshots and evidence: M05_HEPA_SERVICE_HATCH.md / M05_HEPA_HATCH_AUDIT.json.

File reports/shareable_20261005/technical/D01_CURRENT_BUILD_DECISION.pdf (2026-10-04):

ENGINEERING REVIEW / NOT CONSTRUCTION OR ENERGIZATION RELEASE | 1

# AQI Tower — consolidated engineering handoff

D01 / R03M mechanical / E05 control-module fit / 5 October 2026

Decision: ready to hand to the internal engineering team for a build-release review. NOT ready to order all parts, fabricate unchanged drawings or energize. Physical prototypes built: 0.

## Use one current design

Four ARCTIC P14 Max ACFAN00287A fans and two proposed IKEA104.633.30 filters in parallel, in the preserved R03M rectangular cabinet. External12V Noctua adapter/controller/hub are the reference power chain. The larger cylindrical outdoor tower is a later project, not this build.

## What is now closed digitally

Evidence | What it establishes — and does not establish
Mechanical CAD | 493 original assembly objects, STEP and15 drawing files retained. Geometry checks do not approve materials, guards, seals or stability.
E05 control fit | Same300x200x120mm enclosure. Hub rotated/moved, speed controller moved, buttons at X=-15/45/105,Y=55mm. Unchanged assumed rear/cable reservations now clear each other and OEM box geometry. Actual connectors, button stack and supports are unverified.
Software | 1,041 host assertions; default Opta target compile/link passed with official core4.6.0. All relay outputs remain disabled. No physical test or protective control implemented.
Pressure and power | At assumed300m3/h total, conditional filter allowance14.316Pa each. Four fans catalogue16.8W; plus Opta max2W gives18.8W before hub/controller/auxiliaries/startup. The24W path limit is not a measured margin.
Mechanical batch | Actual43mm closing gap /36mm sleeve /7mm offset extracted. Robust seal-window solver and four eight-bolt joint-demand groups,10 tests. The broad ASSUMED tolerance case has no valid fixed stop; gasket force/material capacity remain unknown.
Electrical batch | 24 power /36 wire-drop /8 input scenarios,8 tests. Fan startup multiplier ceiling1.3095x before auxiliaries; an ASSUMED2A-limited fault cannot establish clearing of a2A fuse. Actual fault/inrush data and protective circuit unselected.
Current parts / tools | 28-line current parts register separates exact references/candidates from UNSELECTED items; historicalIH02 retained. One batch-verification command and exact-byte pressure provenance. Visuals/room model remain explanatory, not CFD/CADR proof.

## Control decision

START/STOP/RESET are ordinary inputs. STOP is not emergency stop or isolation. RESET does not start fans. Internal speed adjustment is a disconnected-source preset; close the box before operation. No live knob modification proposed. Current OEM Digest19-42 confirms low-power contacts but gives no numerical minimum switching range.

## How to read this combined PDF

Pages1–2: current decisions and real release blockers. Pages3–4: E05 layout/input review. Pages5–6: preserved E02 bench-control drawing. Pages7–56: earlier50-page engineering handoff, retained as historical evidence. Where its fit/control or board-build status differs, the E05 check record and current target-build JSON govern; older wiring is not released.

ENGINEERING REVIEW / NOT CONSTRUCTION OR ENERGIZATION RELEASE | 2

# What must happen before construction

These are missing engineering inputs and physical acceptance steps, not items that can be marked complete by generating another document. No build approval has been given.

## Five remaining release gates

Gate | Exact deliverable needed / responsible scope
1. Guards / structure | Mechanical reviewer and fabricator: guard reach/strength and seams, material grades, joints, feet, whole-device mass/stability and handling. Revised signed detail drawings and unpowered inspection evidence.
2. Filters / harness | Exact delivered filter tolerance and gasket/compression evidence; fan/extension lead, connector and clamp geometry. Resolve service retention, bypass seal and protected entries. OEM enquiries already sent; replies pending.
3. Rated electrical design | Electrical reviewer: hazard-to-protective-function allocation including restart/recovery; complete selected protection/isolation/switching, startup/fault coordination, actual gauges/terminals/glands, metal-panel treatment, mounts and thermal assessment. Opta software cannot replace this.
4. Actual assembly / commissioning | After revision-specific release and authorized procurement: supplier delivery, fabrication, dry-fit inspection, safe qualified assembly, isolation/stop/restart and abnormal/thermal tests. Signed commissioning precedes performance tests.
5. Performance / acceptance | Test lead: agreed indoor room/targets, calibrated or paid/rented instruments. Record airflow, pressure, bypass, noise, power, temperatures and controlled PM decay/background. No proven CADR or outdoor bubble radius yet.

## No-lab construction route

Use a local cabinet/metal fabricator and qualified electrical assembly/test service in Pune, Hyderabad or Mumbai when chosen. College/NGO funding supports those services and approved parts; no college workshop is assumed. Prepare quotations from current drawings clearly marked REVIEW ONLY; production follows signed release, not this PDF.

## Critical path — no invented dates

Resolve exact component inputs and protective functions → signed mechanical/electrical revision → funding and purchase authorization → delivery/fabrication → unpowered fit and assembly → qualified commissioning → measured performance. Supplier replies and workshop/test capacity control elapsed time; digital compilation alone does not shorten them to a promised date.

## Funding and technical sheets

STAKEHOLDER_FUNDING.xlsx is for actual quotations and milestone funding. TECHNICAL_REVIEW.xlsx and CURRENT_RELEASE_GATES.csv preserve decisions and closure evidence. Stock, prices and dates are UNKNOWN until confirmed. Only released line items can enter a purchase/build authorization.
Unchanged boundary: indoor experimental particle demonstrator. No gas-removal, whole-device HEPA, medical, outdoor heat/rain/tamper or public-clean-air coverage claim. No purchases, supplier messages, hardware flashing or energization performed in this continuation.

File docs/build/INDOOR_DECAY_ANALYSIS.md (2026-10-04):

# Indoor test analysis: off versus on

3 October 2026. EXPLORATORY SOFTWARE — NO PHYSICAL RESULTS.

## In simple words

Particles may settle or leave a room even when the tower is off. This tool compares that natural change with the change when the tower is on. It helps investigate an additional effect rather than crediting the tower for every reduction.

It uses the [measurement recorder's CSV](MEASUREMENT_RECORDING.md), one instrument/channel and **one explicitly selected off/on pair**. No readings exist yet; only synthetic mathematical fixtures were used to test the code. Multiple positions and repeated paired trials still need separate analysis and review.

## What the calculation assumes

Project method from [Build and test sequence](BUILD_AND_TEST.md): fit `ln(particle concentration)` against elapsed hours for each selected window. Decay rate is the negative fitted slope. A conditional clean-air-flow estimate is `room volume * (on decay rate - off decay rate)` in m3/h.

This simple model assumes reasonably well-mixed air, matched ventilation and stable sources with negligible continuing influx/background relative to the selected readings. These are **ASSUMPTIONS**, not facts the software can verify. A nonzero asymptote, changing outdoor pollution, humidity effects, instrument drift, unequal mixing or changing ventilation can bias the result. No background subtraction or asymptotic model is implemented.

The estimate is withheld unless all three assumption declarations in the plan are explicitly true. Declaring them is not scientific validation. A negative estimate remains negative; it is not silently changed to zero. Warnings identify absent calibration references and hypothetical room volumes. There is no automatic performance PASS, statistical significance decision or certification.

For context, [EPA's guide](https://www.epa.gov/indoor-air-quality-iaq/guide-air-cleaners-home) describes CADR as a particle-cleaning measure for indoor room sizing, not gas removal (reviewed 3 October 2026). This project script is our exploratory decay implementation, NOT the EPA method or an AHAM certification procedure. It produces no outdoor radius, network spacing, HEPA-integrity or health claim.

## Use after supervised data collection

Copy `data/monitoring/decay_plan_TEMPLATE.json` into the actual test folder and fill:

- Exact run/instrument identity and room particle channel.
- Room volume and whether measured or assumed; actual dimensions remain UNKNOWN today.
- A usable concentration floor with instrument/test evidence, not an invented detection limit. Physical data requires a positive floor and a reference. The importer cannot authenticate that reference.
- Offset-bearing start/end timestamps for separate off/on windows and the reason for selecting them. Document excluded settling/warm-up periods before examining a favorable outcome; do not cherry-pick windows.
- Honest model-assumption declarations. Leave false if not supported.

Run with actual files (example paths do not exist yet):

```powershell
python scripts/analysis/indoor_decay.py --input data/monitoring/YOUR_RUN/measurements.csv --plan data/monitoring/YOUR_RUN/decay_plan.json --output data/monitoring/YOUR_RUN/decay_exploratory.json
```

Standard library only. All rows must belong to one identified run and one evidence kind. Selected readings must use ug/m3, a matching instrument/channel, correct stage and strictly increasing timestamps. No merging different sensors into one fit. No overlapping off/on windows. A five-reading minimum per window is a software guard, **not an adequate experimental sample-size specification**.

Zero, negative, nonfinite or at/below-floor values stop the analysis; none are clipped, imputed or selectively removed. This may make a low-concentration trial unusable under the model. Output refuses an existing filename and includes input/plan SHA256 provenance, fitted rates, sample durations, R-squared and log residuals for review.

## What remains before a performance report

No confidence interval is implemented. Total uncertainty remains UNKNOWN; room-volume uncertainty, correlated samples, sensor errors, window selection, ventilation differences and trial-to-trial variability are not quantified. R-squared alone does not establish a suitable model. A positive point estimate is not proof of useful improvement.

The test mentor must assess controls, mixing, residuals, calibration/floor, sampling/duration, repeatability and uncertainty before interpreting results. The existing provisional plan calls for at least three paired trials and multiple room locations, not one favorable pair. No pooled multi-trial estimate is supplied here. No deliberate hazardous aerosol challenge or energized testing is authorized by this software.

Exact instruments, installation, mechanical/electrical release and actual data remain pending. Follow the [physical test gates](BUILD_AND_TEST.md). Next: adapt the recorder to confirmed instruments, collect supervised readings after commissioning, then add uncertainty/repeatability analysis using real trial structure.

## Verification

```powershell
python -m unittest discover -s scripts/analysis -p 'test_indoor_decay.py'
python scripts/analysis/indoor_decay.py --help
```

Eight tests use synthetic exponential/constant fixtures only; they cover arithmetic, assumption withholding, negative differences, invalid readings, times/windows, evidence/units, outdoor refusal and physical-floor requirements. Synthetic values are not saved as project measurement results.

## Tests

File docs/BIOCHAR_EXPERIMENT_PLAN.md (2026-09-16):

# AQI Tower Phase 13 — Future Biochar Experiment Plan

**PLAN ONLY — NO EXPERIMENT PERFORMED**  
**PHASE 14 UPDATE — TARGET GAS: FORMALDEHYDE (HCHO)**  
**Use an exact, traceable media grade and institutional laboratory safety controls**

> **Phase 14 controls this future plan.** The frozen points are 50/100/200 µg/m³ HCHO; baseline 100 µg/m³, 25 ± 2 °C, 50 ± 5% RH and 0.10 s EBCT. OVC 4×8 is the non-impregnated control and a traceable HCHO-specific impregnated carbon is the secondary comparison. The early breakthrough metric is `t10` at sustained, time-aligned `C/C0 ≥ 0.10`. Use synchronized continuous HCHO monitors with DNPH–HPLC reference validation. See [`PHASE14_FORMALDEHYDE_TARGET.md`](PHASE14_FORMALDEHYDE_TARGET.md). If this older plan conflicts with that specification, the Phase 14 document governs.

## Objective

Produce the missing pressure-loss, gas-adsorption, breakthrough, and humidity data needed to decide whether a carbon bed is useful in the AQI Tower. Test the primary research candidate first only after a physical sample, SDS, lot certificate, and target-gas requirement are available.

The experiment must not use PM2.5 or PM10 as the primary carbon-bed challenge. The particulate stage and carbon adsorption stage have different purposes.

## Required Before Testing

1. Apply the Phase 14 frozen formaldehyde target and 50/100/200 µg/m³ inlet matrix; do not substitute a generic VOC mixture.
2. Apply the normalized Phase 14 outlet states and primary `t10` breakthrough criterion.
3. Obtain the exact media grade, lot number, SDS, certificate/data sheet, and supplier packing instructions.
4. Complete an institutional chemical risk assessment, ventilation plan, gas-cylinder procedure, leak test, emergency response, and waste plan.
5. Select calibrated gas analysis suitable for the compound and concentration. A broad low-cost “VOC sensor” is not a substitute for compound-specific analysis.

## Common Test Records

For every run record:

- media name, lot, precursor, activation/impregnation, particle-size distribution;
- dry and as-tested mass, moisture, bulk density, packing method, and bed settling;
- column inside diameter, bed depth, bed volume, support screens, and seal arrangement;
- airflow at test temperature/pressure, superficial velocity, temperature, and RH;
- upstream/downstream concentration and analyzer calibration;
- pressure drop, elapsed time, and replicate identifier;
- blank-column result, leakage check, and mass balance where possible.

## A. Pressure Drop

### Question

What pressure loss does the exact packed medium create as a function of superficial velocity, bed thickness, and packing state?

### Apparatus

- Straight transparent or metal test column with an inside diameter large enough to reduce wall effects relative to the media particle diameter.
- Uniform air distributor, retaining screens, upstream/downstream static-pressure taps, differential-pressure instrument, temperature/RH sensor, and calibrated airflow measurement.
- Clean, dry air for the baseline; no target gas is required for the first hydraulic tests.

### Proposed matrix

- At least three bed thicknesses, selected to bracket plausible cassette depths; suggested planning levels are 25, 50, and 100 mm until requirements are approved.
- At least six superficial velocities spanning the intended operating range. Begin safely below the official OVC graph limit and increase only while the test rig and fan remain within ratings.
- Test both freshly poured/loose packing and a repeatable settled packing state.
- Minimum three independently repacked repeats per condition.
- Run an empty-column/support-screen baseline and subtract only the measured fixture loss.

### Outputs

- ΔP versus superficial velocity for each bed depth and packing state.
- ΔP per unit bed length where scaling is demonstrated.
- Repeatability, hysteresis after settling, and uncertainty.
- Measured bulk density and, if feasible, bed void fraction.
- A Darcy-only fit if the measured relation is linear; otherwise a Darcy–Forchheimer fit. Do not force either model.

The activated-carbon industry method measures packed-bed pressure drop at multiple gas velocities and reports it per bed length; its geometry and calibration principles should inform the rig ([industry pressure-drop method](https://www.activatedcarbon.org/wp-content/uploads/2025/02/Test_method_for_Activated_Carbon_86.pdf)).

## B. Adsorption

### Question

For the selected gas, how do inlet and outlet concentrations differ under a documented flow, bed, temperature, and humidity condition?

### Procedure

1. Condition the media using the supplier-approved procedure and record its mass/moisture.
2. Establish clean carrier-air flow, temperature, and RH through the sealed column.
3. Introduce a certified target-gas challenge at the approved concentration.
4. Measure concentration upstream and downstream continuously or at a justified interval.
5. Measure pressure drop throughout the run.
6. Continue through the pre-approved breakthrough endpoint or a safe maximum duration.
7. Repeat with a blank column and at least three media replicates.

### Outputs

- Time series of upstream and downstream concentration.
- Single-pass concentration ratio at each time, always tied to the test condition.
- Adsorbed mass per dry media mass from a documented inlet/outlet mass balance.
- Temperature rise across the bed and any visible channeling, settling, or dust release.

Do not translate a laboratory capacity into a guaranteed real-world removal percentage or service interval.

## C. Breakthrough

### Question

When does downstream concentration begin to rise as available adsorption capacity is consumed?

### Required analysis

- Plot normalized concentration `C_out/C_in` against elapsed time and treated gas volume.
- Predefine reporting points such as 5%, 10%, and 50% `C_out/C_in`; these are proposed experimental markers, not product guarantees.
- Report breakthrough capacity, saturation capacity if reached safely, and the mass-transfer-zone behavior.
- Repeat at more than one flow/empty-bed contact time and at more than one inlet concentration if the target application spans those conditions.
- Check whether a second guard bed is needed for safe experimental containment; this is a test-safety decision, not a tower design decision.

EPA distinguishes saturation, breakthrough, heel, and working capacities and emphasizes outlet concentration and regeneration conditions as performance indicators ([EPA carbon-adsorber guidance](https://www.epa.gov/air-emissions-monitoring-knowledge-base/monitoring-control-technique-activated-carbon-adsorber)).

## D. Humidity

### Question

How does water vapor change pressure loss, breakthrough time, and capacity for the exact target gas and medium?

### Proposed comparison

- Use at least three controlled RH levels representing dry, typical, and high-humidity service; exact setpoints must follow the selected application.
- Hold gas concentration, temperature, flow, bed mass, depth, and packing constant.
- Equilibrate the bed at each RH before introducing the target gas.
- Record water uptake where feasible and test for condensation.
- For impregnated media, follow manufacturer humidity limits because water can help or inhibit reaction chemistry.

Published rice-husk activated-carbon data show lower VOC adsorption coefficients at 90% RH than at about 55% RH, while a specialized hydrophobic bamboo-derived carbon retained different fractions for different VOCs. These results justify testing humidity but do not supply a correction factor for the selected product ([Li et al., 2016](https://doi.org/10.1016/j.seppur.2016.06.029); [Rong et al., 2023](https://doi.org/10.1016/j.cej.2023.141979)).

## Safety and Disposal

- Do not conduct student exposure tests or release challenge gas to a room.
- Use a ventilated enclosure/fume extraction and downstream guard treatment approved for the selected chemical.
- Treat spent media according to the adsorbate and SDS; it may become hazardous waste.
- Do not attempt thermal or chemical regeneration in a student laboratory without a separate reviewed process.
- Control dust and ignition sources. Wet activated carbon can deplete oxygen in confined spaces ([OVC safety statement](https://www.calgoncarbon.com/app/uploads/DS-OVC4x815-EIN-E2.pdf)).

## Acceptance Gate for CFD Data

Pressure data become CFD-ready only when:

1. the exact grade and packing state are documented;
2. the measured velocity range covers the intended tower operating range;
3. repeated ΔP measurements have acceptable uncertainty;
4. bed-thickness scaling is checked; and
5. the selected Darcy or Darcy–Forchheimer fit reproduces held-out measurements.

Adsorption transport modelling requires an additional validated breakthrough dataset. Pressure readiness alone does not establish adsorption performance.

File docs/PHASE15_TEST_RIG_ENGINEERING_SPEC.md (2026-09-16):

# AQI Tower Phase 15 — Test-Rig Engineering Specification

**PHASE 15 — ENGINEERING PREPARATION ONLY**
**STATUS: SPECIFICATION DOCUMENT — NO EXPERIMENT PERFORMED, NO CFD RUN**
**Date: 2026-09-06**
**Supersedes: nothing. Supplements Phase 14 frozen requirements.**

All evidence labels follow the Phase 14 convention:
- **PROPOSED PROJECT TARGET** — selected requirement, must be verified experimentally
- **ENGINEERING ASSUMPTION** — provisional; must be checked before use
- **VERIFIED PRODUCT** — product confirmed to exist with cited evidence
- **CANDIDATE PRODUCT** — product believed to be available; procurement not confirmed
- **GENERIC REQUIREMENT** — functional need; specific product not yet selected
- **REQUIRES QUOTE** — specification clear but price/availability not confirmed
- **UNKNOWN** — requires investigation before deciding

---

## 1. Scope and Purpose

Phase 15 converts the Phase 14 experimental requirements into a buildable, procurement-ready engineering system.

**Phase 15 does NOT:**
- Run CFD
- Invent adsorption coefficients, breakthrough times, removal efficiencies, or bed-life estimates
- Select a final tower carbon-bed geometry
- Claim CADR
- Produce or use formaldehyde
- Claim that OVC 4×8 or FORMASORB is suitable for the AQI Tower

**Phase 15 DOES:**
- Define the exact packed-bed column architecture for the controlled bench test
- Select a column diameter with documented justification
- Tabulate required flows, EBCTs, and bed volumes for all Phase 14 matrix conditions
- Specify pressure, flow, HCHO, T/RH, and analytical measurement architectures
- Define the DNPH–HPLC reference workflow
- Verify the current SFA30 documentation
- Define HCHO generation system requirements (not a specific commercial device)
- Document media containment, sealing, and blank/zero-air procedures
- Produce a procurement table with availability classification for all items
- Provide three cost tiers (minimum viable / recommended / reference-grade)
- Define a synchronized data schema

---

## 2. Rig Architecture Overview

### 2.1 Conceptual flow path

```
[Zero/clean air supply]
        |
        v
[Humidity conditioner]  ← RH control branch
        |
        v
[HCHO generation / injection point]   (institutional laboratory only; Section 8)
        |
        v
[Static mixer / conditioning length]
        |
        v
[Upstream T/RH sensor + SFA30 #1]    ← upstream sample port
        |
        v
[DNPH upstream cartridge port]
        |
        v
[Packed-bed test column]
  - inlet distributor
  - upstream pressure tap
  - media retaining mesh
  - granular GAC bed (OVC 4×8 or FORMASORB)
  - downstream retaining mesh + support
  - downstream pressure tap
        |
        v
[Downstream T/RH sensor + SFA30 #2]  ← downstream sample port
        |
        v
[DNPH downstream cartridge port]
        |
        v
[Flow measurement device]
        |
        v
[Fan / flow controller]
        |
        v
[HCHO exhaust capture / scrubber → facility exhaust]
```

### 2.2 Zero-air / blank path

A bypass valve before the HCHO injection point routes clean air through the entire downstream rig without challenge. This path is used for:
- System leak checks
- Transport-delay measurement
- Instrument co-location and zero verification
- Blank DNPH cartridge collection

No HCHO is introduced during blank tests.

### 2.3 Rig material constraints

All wetted surfaces downstream of the HCHO injection point must have documented HCHO compatibility and low HCHO adsorption. Preferred materials:
- **Tubing:** PTFE or stainless steel 316 — **GENERIC REQUIREMENT**
- **Fittings:** stainless steel or PTFE-lined — **GENERIC REQUIREMENT**
- **Column body:** stainless steel 316 or borosilicate glass — **GENERIC REQUIREMENT**
- **Seals/gaskets:** PTFE or Viton — **GENERIC REQUIREMENT**
- **Avoid:** PVC, natural rubber, silicone tubing, untreated acrylic — each can adsorb or off-gas HCHO significantly at ppb levels

---

## 3. Packed-Bed Column Geometry Analysis

### 3.1 Wall-effect criterion

The wall-effect criterion for packed beds requires the column internal diameter to be at least 10× the maximum particle diameter of the media.

For OVC 4×8 US mesh:
- 4 mesh = 4.75 mm screen; 8 mesh = 2.36 mm screen
- `d_max = 4.75 mm` (as defined by the 4-mesh upper screen) — **MANUFACTURER SPECIFICATION**
- Minimum ID = 10 × 4.75 mm = **47.5 mm** — **DERIVED ENGINEERING ASSUMPTION**

Actual particle-size distribution may differ from the mesh nominal; measure the as-received lot before testing.

### 3.2 Column comparison table

All values are **DERIVED** from the Phase 14 velocity matrix and column geometry.

#### Area and wall-effect ratio

| Column ID | Cross-section area | ID / d_max (d_max = 4.75 mm) | Wall-effect criterion |
|---:|---:|---:|---|
| 50 mm | 19.63 cm² | **10.5** | Marginal — just meets ≥10× rule |
| 75 mm | 44.18 cm² | **15.8** | Good — recommended minimum |
| 100 mm | 78.54 cm² | **21.1** | Excellent — larger flows required |

#### Flow required (L/min) — Q = A × U_s

| Superficial velocity U_s | 50 mm ID | 75 mm ID | 100 mm ID |
|---:|---:|---:|---:|
| 0.13 m/s | 15.3 L/min | 34.5 L/min | 61.3 L/min |
| 0.26 m/s | 30.6 L/min | 68.9 L/min | 122.5 L/min |
| 0.52 m/s | 61.3 L/min | 137.8 L/min | 245.0 L/min |
| 0.80 m/s | 94.3 L/min | 212.2 L/min | 376.9 L/min |
| 1.05 m/s | 123.7 L/min | 278.4 L/min | 494.8 L/min |

**Derivation:** Q (L/min) = A (m²) × U_s (m/s) × 1000 × 60

#### Bed volumes (mL) — V_bed = A × L

| Bed depth L | 50 mm ID | 75 mm ID | 100 mm ID |
|---:|---:|---:|---:|
| 26 mm | 51.0 mL | 114.9 mL | 204.2 mL |
| 52 mm | 102.1 mL | 229.7 mL | 408.4 mL |
| 104 mm | 204.1 mL | 459.5 mL | 816.8 mL |

#### EBCT matrix — EBCT = L / U_s (seconds)

| | U_s = 0.13 m/s | U_s = 0.26 m/s | U_s = 0.52 m/s | U_s = 0.80 m/s | U_s = 1.05 m/s |
|---:|---:|---:|---:|---:|---:|
| L = 26 mm | **0.200 s** | **0.100 s** (baseline) | **0.050 s** | 0.033 s | 0.025 s |
| L = 52 mm | 0.400 s | **0.200 s** | **0.100 s** | 0.065 s | 0.050 s |
| L = 104 mm | 0.800 s | 0.400 s | **0.200 s** | 0.130 s | 0.099 s |

Bold values are the Phase 14 proposed EBCT levels (0.05, 0.10, 0.20 s) and their depth/velocity combinations. EBCT does not depend on column diameter.

### 3.3 Column diameter selection and justification

#### 50 mm ID assessment

**Advantages:** lowest flows (15–124 L/min), smallest media mass, lowest HCHO consumption per run.
**Disadvantages:** wall-effect ratio = 10.5 is the minimum boundary; any particle batch with a slightly coarser tail will violate it. At 0.52 m/s the flow (61 L/min) is still modest.
**Decision:** acceptable as a minimum viable size if the exact lot is screened and the d_max is confirmed ≤ 4.75 mm.

#### 75 mm ID assessment — **RECOMMENDED**

**Advantages:** wall-effect ratio = 15.8 provides a comfortable margin over the ≥10× criterion. Baseline condition (0.26 m/s) requires 68.9 L/min — achievable with a 0–100 L/min rotameter and a suitable fan or lab air supply. All five velocity points fall within 0–280 L/min, manageable with available Indian lab equipment. Bed volume (115–460 mL) gives sensible media masses for a student experiment.
**Disadvantages:** higher flows than 50 mm, more HCHO required per unit time.
**Decision:** **75 mm ID is the recommended primary column diameter** — **PROPOSED PROJECT TARGET**.

#### 100 mm ID assessment

**Advantages:** excellent wall-effect margin, larger bed volume reduces screen-to-media ratio concerns.
**Disadvantages:** baseline flow = 122.5 L/min, high-velocity points reach 500 L/min — requires a large lab fan and high-capacity MFC or blower. More expensive column hardware. Higher HCHO consumption per run.
**Decision:** not recommended for initial student-scale work; revisit if a later phase needs larger throughput or better flow uniformity.

### 3.4 Media mass estimates (75 mm ID column)

No bulk density is confirmed for the OVC 4×8 lot yet. The following uses a placeholder bulk density of **450–550 kg/m³** (dense-packed GAC, typical literature range) as an **ENGINEERING ASSUMPTION** until the actual lot is weighed.

| Bed depth | Bed volume | Estimated dry media mass (at 450 kg/m³) | At 550 kg/m³ |
|---:|---:|---:|---:|
| 26 mm | 114.9 mL | ~52 g | ~63 g |
| 52 mm | 229.7 mL | ~103 g | ~126 g |
| 104 mm | 459.5 mL | ~207 g | ~253 g |

Measure actual bulk density from the received lot: fill a graduated cylinder with a known dry mass and read settled volume. Record loose and settled density separately.

---

## 4. Media Containment Design

### 4.1 Column body

- **Material:** stainless steel 316 tube with flanged end caps, or borosilicate glass chromatography column body with PTFE end fittings — **GENERIC REQUIREMENT**
- **Internal diameter:** 75 mm (as selected above)
- **Total column length:** ≥ 200 mm to accommodate 104 mm max bed plus support screens, settling length, and pressure-tap spacing
- **Pressure rating:** the rig operates near atmospheric; 1 bar gauge is adequate
- **Transparency is desirable** but not required for pressure-drop tests; it allows visual detection of channeling, media movement, or flooding. If a glass column is used, verify chemical compatibility with HCHO and the carrier air.
- Flanges must allow interchangeable end caps for different screen/distributor configurations

### 4.2 Inlet distributor

- **Purpose:** produce a uniform velocity profile across the full column cross-section before the media bed
- **Type:** sintered metal disc (SS316), perforated plate (≥ 30% open area), or woven wire mesh (300–500 µm opening) — **GENERIC REQUIREMENT**
- **Location:** at the inlet face of the column, upstream of the media
- A straight entry length of ≥ 1× column diameter (≥ 75 mm) between the inlet fitting and the distributor is recommended

### 4.3 Media retaining screens

- **Upper screen (inlet side of bed):** retains media in place; must not obstruct flow significantly
  - Opening: ≤ d_min = 2.36 mm for OVC 4×8; use ≤ 2.0 mm opening to be safe
  - Material: SS316 woven wire — **GENERIC REQUIREMENT**
- **Lower screen (outlet side):** same specification; also catches fines
- Additional filter paper (Whatman Grade 1 or equivalent, SS316 disc holder) between screen and end cap catches dust if media has significant fines
- Screens must be documented as low-HCHO-adsorption materials

### 4.4 Pressure tap locations

- **Upper tap (UP):** in the column wall at the inlet face of the media (above upper screen, below distributor)
- **Lower tap (DOWN):** in the column wall at the outlet face of the media (above lower screen)
- Tap geometry: 1–2 mm diameter drilled port, flush with inner column wall (no burr), connecting to 1/8" SS or PTFE tubing leading to the differential pressure sensor
- Tap-to-tap distance = settled bed depth L (measure after each packing); record this as the effective `L` for the ΔP/L calculation

### 4.5 Sample ports

- **Upstream gas sample:** Swagelok-type or PTFE-sleeved bulkhead fitting, 6 mm OD, immediately upstream of the media bed (before upper screen) — connects to upstream SFA30 and DNPH port via a T-junction
- **Downstream gas sample:** same fitting, immediately downstream of lower screen — connects to downstream SFA30 and DNPH port

DNPH and SFA30 must draw from the same port without interfering with the main flow. A T-piece with the DNPH pump pulling side-stream at << 5% of total flow is acceptable; verify that the side-draw does not reduce main column flow below the target U_s by more than ±2%.

### 4.6 Sealing strategy

- All flanged joints: PTFE spiral-wound gaskets or flat PTFE sheet gaskets — **GENERIC REQUIREMENT**
- Column end caps: O-ring sealed, Viton or PTFE — **GENERIC REQUIREMENT**
- Tubing connections: compression-fit Swagelok or equivalent (SS316) or PTFE push-fit
- Perform a mandatory **blank leak test** before every HCHO campaign: pressurize the sealed column + rig to ~ 1 kPa above atmospheric with clean air, then monitor for pressure decay or use a portable HCHO monitor around all joints

### 4.7 Media filling and settling procedure (to be developed before first test)

1. Dry media to constant mass at 110°C; cool to room temperature in a desiccator.
2. Tare the column assembly (without media).
3. Pour media slowly into the upright column through a funnel; record poured height.
4. Tap the column 10× with a rubber mallet on the side; record settled depth.
5. Level the surface gently; install upper screen and end cap.
6. Weigh the assembled column; record net dry media mass.
7. Calculate settled bulk density: mass / (A × settled depth).
8. Photo-document before sealing.
9. Replicate this procedure independently for each of the three required packing replicates.

---

## 5. Pressure Measurement Architecture

### 5.1 Purpose

Measure `ΔP` versus superficial velocity versus bed depth for each media and packing replicate, to provide the future Darcy–Forchheimer fitting data. The coefficients themselves are **NOT calculated in Phase 15** — they must come from measurements.

### 5.2 Required measurement

- **Differential pressure:** measured between the upstream and downstream pressure taps (across the packed bed only — not across the distributor)
- **Empty-column correction:** the empty column with screens installed but no media must be measured at every velocity point; this fixture ΔP is subtracted from the packed-bed measurement
- **Velocity range:** 0.13, 0.26, 0.52, 0.80, 1.05 m/s — as defined by Phase 14

### 5.3 Pressure sensor specification

| Parameter | Requirement | Justification |
|---|---|---|
| Range | 0 to 500 Pa differential | Covers all bed depths and velocities including extrapolated 1.05 m/s at 104 mm; leaves margin for unexpected high-resistance packing |
| Resolution | ≤ 1 Pa | Required to resolve ΔP at low velocity/short bed (estimated 2–5 Pa at 0.26 m/s, 26 mm bed) |
| Accuracy | ≤ 2% FS (≤ 10 Pa full-scale error) | Adequate for Darcy–Forchheimer fitting; confirm against a reference water manometer |
| Operating temperature | 15–40°C | Covers laboratory range |
| Output | Analog 4–20 mA or digital (I²C / SPI) | Compatible with chosen DAQ system |
| Wetted parts | SS316 or PTFE | HCHO compatibility required if on the HCHO side of the rig |
| Status | **GENERIC REQUIREMENT** — no specific product selected |

**India procurement note:** Sensirion SDP510 (+500 Pa range, I²C, compact) or SDP600-500Pa are **CANDIDATE PRODUCTS** available through RS Components India — verify current India stock and price. Industrial differential pressure transmitters (e.g., Dwyer 616, Honeywell HSC series) are available through IndiaMART distributors at **REQUIRES QUOTE**.

### 5.4 Tap geometry and tubing

- Pressure tap tubes: 3–6 mm OD SS or PTFE, ≤ 500 mm length from tap to sensor
- Tubes must be dry and free of condensate before each test; tilt column slightly if liquid could accumulate in taps
- Purge tap lines with clean dry air and zero the sensor before each velocity point

### 5.5 Measurement procedure

1. **Zero check:** with no flow, record DP reading; it must be within ±1 Pa of zero after zeroing.
2. **Empty-column baseline:** insert screens only (no media), run each velocity point in increasing order, wait for steady state (≥ 30 s), record 10 readings, take mean.
3. **Packed column:** install media, repeat at each velocity point.
4. **Hysteresis check:** repeat one velocity point after decreasing flow.
5. **Fixture-corrected ΔP** = packed-column ΔP − empty-column ΔP at the same velocity.
6. **Replicates:** three independently repacked beds per material per depth.
7. Record air temperature and ambient pressure at each point for density correction if needed.

### 5.6 Independent verification

Cross-check the sensor reading at ≥ 2 points against a calibrated inclined water manometer or electronic reference calibrator. If the deviation exceeds 5 Pa at any check point, recalibrate the sensor before continuing.

---

## 6. Airflow Measurement Architecture

### 6.1 Distinction from tower airflow

- **Tower operating flow (Phase 10B):** Q ≈ 1332 m³/h through the full GEO_C tower — this is a CFD result, not a bench measurement
- **HEPA face velocity:** 1.053 m/s across the 0.3516 m² filter face — also a CFD-derived value
- **Bench superficial velocity:** the velocity at the 75 mm ID column cross-section during the experiment — the quantity controlled and reported in Phase 15

These are different quantities in different systems. Never substitute one for another.

### 6.2 Bench airflow measurement method

For pressure-drop tests (clean air, no HCHO):

| Method | Range | Suitability |
|---|---|---|
| Calibrated rotameter (acrylic, 0–100 L/min) | 0–100 L/min | Covers U_s = 0.13–0.26 m/s for 75 mm column; **CANDIDATE PRODUCT** ~₹1,950 (IndiaMART) |
| Calibrated rotameter (0–300 L/min) | 0–300 L/min | Covers U_s up to 0.52–0.80 m/s for 75 mm column; **CANDIDATE PRODUCT** — REQUIRES QUOTE |
| Thermal mass flow meter | 0–300 L/min | Higher accuracy; suitable for breakthrough tests too; **REQUIRES QUOTE** |
| Needle valve + pressure differential across orifice plate | Custom range | Can be accurate but requires calibration; **GENERIC REQUIREMENT** |

For breakthrough tests (HCHO challenge present), the flow measurement device must be placed **downstream of the scrubber** where no HCHO remains, or use a thermal mass flow element that is chemically inert to HCHO and is placed upstream before the HCHO injection point.

### 6.3 Flow control

- **Needle valve + rotameter** combination is the minimum viable control approach for pressure-drop tests
- **MFC (thermal mass flow controller)** is required if breakthrough runs demand constant flow over hours; a 0–100 L/min MFC for zero air and a smaller 0–5 L/min MFC for the HCHO standard gas stream are appropriate for the 75 mm baseline condition — **REQUIRES QUOTE** (India MFC suppliers: Alicat, Bronkhorst, Sierra — none confirmed at current India price)
- Report the **actual measured flow** at each data point, not only the setpoint

### 6.4 Superficial velocity calculation

`U_s (m/s) = Q (m³/s) / A_column (m²)`

For 75 mm ID column: A = 44.18 × 10⁻⁴ m²

| Target U_s | Target Q (75 mm) | Rotameter setting |
|---:|---:|---|
| 0.13 m/s | 34.5 L/min | Set with needle valve; read rotameter |
| 0.26 m/s | 68.9 L/min | Same |
| 0.52 m/s | 137.8 L/min | Requires 0–150 or 0–300 L/min instrument |
| 0.80 m/s | 212.2 L/min | Requires 0–300 L/min instrument |
| 1.05 m/s | 278.4 L/min | Requires 0–300 L/min instrument |

Note: rotameter readings depend on gas density; correct for temperature and pressure if the reading medium differs from the calibration condition.

---

## 7. HCHO Generation System Requirements

### 7.1 Safety preface

Formaldehyde is an IARC Group 1 human carcinogen and a respiratory sensitizer. Intentional HCHO generation is prohibited in any space that is not:

1. An institutionally managed chemical laboratory
2. Equipped with a suitable fume hood or exhausted enclosure certified for the concentration and quantity used
3. Approved in writing by the responsible institutional safety authority
4. Staffed by trained personnel with current HCHO training
5. Equipped with an independent calibrated area HCHO alarm monitor

The rig described in this document defines what system specification to request from an approved institutional laboratory. It does not authorize student construction or operation of a generation system outside institutional controls.

### 7.2 Explicitly prohibited generation methods

Exactly as stated in Phase 14:

- Open hotplate with formalin solution
- Heated paraformaldehyde in open container
- Polymer off-gassing (POM, MDF, pressed-wood)
- Room dosing or occupied-space generation
- Uncontrolled cylinder discharge without calibrated dilution
- Any method without downstream HCHO destruction/capture

### 7.3 Acceptable generation architectures

**Architecture A — Certified gas cylinder with dynamic dilution (recommended for student lab)**

Use a traceable HCHO calibration gas cylinder (e.g., 5 ppm HCHO in N₂ or air at ±2% uncertainty, NIST-traceable). Dilute with calibrated clean/zero air to the required challenge concentration.

Example dilution calculation for 75 mm baseline condition (100 µg/m³ challenge, 68.9 L/min total):

- 100 µg/m³ = 81.3 ppb at 25°C, 1 atm
- If standard gas is 5 ppm (5000 ppb): dilution ratio = 5000/81.3 = 61.5
- Standard gas flow = total flow / 61.5 = 68.9/61.5 = 1.12 L/min
- Zero air flow = 68.9 − 1.12 = 67.8 L/min

These flows are controllable with two calibrated MFCs. The mixture enters a static mixer before the test column inlet.

**Status of standard gas cylinder:** REQUIRES QUOTE — contact BOC India, Linde India, or National Chemical Laboratory Pune for 5–50 ppm HCHO/N₂ certified gas.

**Architecture B — Permeation tube system**

A calibrated HCHO permeation tube in a temperature-controlled oven provides a known permeation rate (ng/min). The permeation stream is swept by a carrier flow and diluted to the challenge concentration. Permeation-based generation is described in OSHA Method 52 and NIST literature as a validated traceable approach.

Status: **REQUIRES QUOTE** for both the permeation tube (Kin-Tek, VICI Metronics) and the controller oven. India availability **UNKNOWN**.

**Architecture C — Validated electrochemical generator**

Some laboratory instruments generate HCHO electrochemically from methanol oxidation at a calibrated rate. These require validation, regular standard-gas verification, and are typically higher cost.

Status: **UNKNOWN** — not recommended for initial setup without institutional analytical chemistry support.

### 7.4 Required system elements (for Architecture A)

| Element | Specification | Status |
|---|---|---|
| Standard HCHO gas cylinder | ≥ 5 ppm HCHO in zero air or N₂; NIST/NPL-traceable; ±2% certified uncertainty; SDS | REQUIRES QUOTE |
| MFC for standard gas | 0–2 L/min range, air/N₂ compatible, calibrated; ±1% FS | REQUIRES QUOTE |
| MFC for zero air | 0–80 L/min range; calibrated ±1% FS | REQUIRES QUOTE |
| Zero/clean air supply | Compressed air with activated-carbon trap + molecular sieve (HCHO blank < 5 µg/m³ verified) | GENERIC REQUIREMENT |
| Static mixer | 100–200 mm SS or PTFE tube with turbulence inserts or a baffle | GENERIC REQUIREMENT |
| RH conditioning | Humidifier (Nafion tube or bubbler) + RH sensor; delivers 50 ± 5% RH into the mixing volume | GENERIC REQUIREMENT |
| Downstream capture | Carbon scrubber (Purafil or equivalent HCHO-rated media) → facility exhaust | GENERIC REQUIREMENT |
| Area HCHO monitor | Calibrated, independent from research sensors; alarm at ≥ 0.05 ppm | REQUIRES QUOTE |
| Fume hood / enclosure | Institutional certified, ≥ 0.3 m/s face velocity, exhausted | GENERIC REQUIREMENT |

### 7.5 HCHO challenge verification

Do not rely solely on the calculated dilution ratio to confirm the actual challenge concentration. Before directing challenge air through the test bed:

1. Run challenge air through the bypass path (no media) with both upstream and downstream SFA30s in-line.
2. Compare SFA30 upstream and downstream readings — they must agree within ±5% on the bypass.
3. Collect one upstream DNPH reference sample during the stabilization period.
4. Analyze the DNPH sample to verify that the actual C_in matches the calculated generation rate.
5. Only after verified stable C_in should the HCHO stream be routed through the test bed.

---

## 8. SFA30 — Verified Current Documentation

**Source: Sensirion SFA30 Datasheet v1.3, January 2025 — VERIFIED PRODUCT**
[https://sensirion.com/media/documents/DEB1C6D6/6789009D/GAS_DS_SFA30_D1.pdf](https://sensirion.com/media/documents/DEB1C6D6/6789009D/GAS_DS_SFA30_D1.pdf)
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

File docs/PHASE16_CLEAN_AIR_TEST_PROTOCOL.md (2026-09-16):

# AQI Tower Phase 16 — Clean-Air Pressure-Drop Test Protocol

**PHASE 16 — CLEAN-AIR PRESSURE-DROP RIG ONLY**
**STATUS: SPECIFICATION — NO EXPERIMENT PERFORMED, NO CFD RUN**
**Date: 2026-09-06**

---

## 1. Purpose and Scope

This protocol defines the complete procedure for measuring clean-air pressure drop across a packed bed of granular activated carbon (GAC) in the Phase 16 bench-scale rig. The output is a set of ΔP–U_s data pairs at three bed depths, fit to the Darcy–Forchheimer equation to yield empirical coefficients for future use in flow modelling and HCHO breakthrough test design.

**This protocol does not involve HCHO, any toxic gas, or any hazardous chemical.** Activated carbon is non-toxic in normal handling; standard dust precautions (gloves, dust mask) are required. Compressed air is the sole gas supply.

### 1.1 What this protocol produces

- Fixture (empty-rig) ΔP baseline as a function of flow (Stage A)
- Corrected bed ΔP = ΔP_total − ΔP_fixture for three bed depths (Stages B, C, D)
- Three independently repacked replicates per bed depth
- Fitted Darcy–Forchheimer coefficients a (Pa·s/m²) and b (Pa·s²/m³) from measurements only
- QC acceptance/rejection decisions for each replicate

### 1.2 Column and media reference

| Parameter | Value |
|---|---|
| Column ID | 75.0 mm |
| Column cross-sectional area A | 44.18 × 10⁻⁴ m² (4.418 × 10⁻³ m²) |
| Media | OVC 4×8 (Kuraray / Calgon Carbon), or equivalent GAC from same lot |
| Target bed depths | 26, 52, 104 mm |
| Target superficial velocities U_s | 0.13, 0.26, 0.52, 0.80, 1.05 m/s |
| Corresponding flows Q (75 mm col.) | 34.5, 68.9, 137.8, 212.1, 278.4 L/min |
| Ambient condition target | 25 ± 5°C, any RH (record measured value) |

---

## 2. Pre-Test Checklist

Complete before every test session (Stage A, B, C, or D).

| Item | Required state | Verified by |
|---|---|---|
| Media lot certificate | In hand with lot number, bulk density, particle size | Operator |
| Media dry mass | Confirmed ≤ 0.5% mass change between two consecutive 1-hour oven drying cycles at 105°C | Balance reading |
| Column assembly | End caps and O-rings seated; all bolts/clips tightened uniformly | Visual + bubble test |
| Bubble test | All joints at 200 Pa supply: ≤ 5 bubbles/minute at each joint | Soapy water |
| SDP810 zero | 0 ± 1 Pa with both taps open to atmosphere | DAQ reading |
| Testo 510 zero | 0 ± 1 Pa | Testo display |
| DAQ clock | NTP-synced (if network) or DS3231 RTC set from phone reference within 60 s | System time check |
| CSV header written | All mandatory header fields completed before logging starts | File inspection |
| Rotameter calibration check | Last calibration ≤ 3 months; correction factor noted in session header | Calibration record |
| Safety | Gloves worn for media handling; dust mask worn during packing and unpacking; no open flame near carbon | Operator |

---

## 3. Data Schema — Phase 16 Clean-Air

Every logged row must contain the following fields. No HCHO fields are included; they are defined in the Phase 15 Data Acquisition Specification for HCHO work.

| Field | Units | Source |
|---|---|---|
| `timestamp_utc` | ISO 8601 string | Raspberry Pi clock (NTP or RTC) |
| `run_id` | String (e.g., `RUN_P16_A_20261025_001`) | Operator |
| `stage` | String (`A`, `B`, `C`, or `D`) | Operator |
| `replicate` | Integer (1, 2, or 3) | Operator |
| `media_name` | String (`OVC4x8` or `EMPTY`) | Operator |
| `media_lot` | String | Operator (from certificate) |
| `media_dry_mass_g` | g (float) | Operator (weighed before run) |
| `settled_bed_depth_mm` | mm (float) | Operator (measured before sealing upper end cap) |
| `target_velocity_ms` | m/s (float) | Operator (from velocity sequence) |
| `flow_lpm` | L/min (float) | Rotameter reading (corrected if needed) |
| `dp_sdp810_Pa` | Pa (float) | SDP810 reading |
| `dp_testo510_Pa` | Pa (float or NaN) | Testo 510 reading (NaN if not connected at this moment) |
| `ambient_T_degC` | °C (float) | SHT40 at column inlet |
| `ambient_RH_pct` | % RH (float) | SHT40 at column inlet |
| `sdp810_status` | Integer (0 = OK) | SDP810 status register |
| `operator` | String | Operator |
| `notes` | String | Inline alarms, valve events, anomalies |

### 3.1 Session header

Written once per run file:

```
# AQI-TOWER PHASE 16 CLEAN-AIR TEST SESSION
# run_id: RUN_P16_B_20261025_001
# stage: B
# replicate: 1
# operator: [name]
# media_name: OVC4x8
# media_lot: [lot ID]
# media_dry_mass_g: [value]
# settled_bed_depth_mm: [measured value]
# column_id_mm: 75.0
# column_material: ACRYLIC
# target_velocities_ms: 0.13 0.26 0.52 0.80 1.05
# rotameter_model: [model]
# rotameter_cal_date: [date]
# rotameter_correction_factor: [value or 1.0 if within tolerance]
# sdp810_serial: [if labelled]
# sdp810_zero_check_Pa: [reading before run]
# testo510_zero_check_Pa: [reading before run or N/A]
# sht40_serial: [if labelled]
# fixture_dp_Pa_at_34.5lpm: [from Stage A]
# fixture_dp_Pa_at_68.9lpm: [from Stage A]
# fixture_dp_Pa_at_137.8lpm: [from Stage A]
# fixture_dp_Pa_at_212lpm: [from Stage A]
# fixture_dp_Pa_at_278lpm: [from Stage A or N/A if not yet run]
# ambient_T_start_degC: [value]
# ambient_RH_start_pct: [value]
# ambient_pressure_kPa: [value from phone/lab barometer]
# notes: [pre-run conditions, any deviations]
```

---

## 4. Stage A — Empty-Rig Baseline

### 4.1 Purpose

Measure the ΔP contribution of the empty column (fittings, screens, end caps, flow-path tubes) at each target flow. This is subtracted from Stage B, C, D totals to isolate the bed ΔP.

### 4.2 Assembly

- Install two mesh screens (one at each end) with no media between them.
- Seat end caps with O-rings. Tighten uniformly.
- Connect pressure taps to SDP810 and Testo 510.
- Confirm Stage A session header written.

### 4.3 Velocity sequence

Run velocity points in ascending order:

| Step | Target U_s (m/s) | Target Q (L/min) | Stabilization time |
|---:|---:|---:|---|
| A1 | 0.13 | 34.5 | 3 min |
| A2 | 0.26 | 68.9 | 3 min |
| A3 | 0.52 | 137.8 | 3 min |
| A4 | 0.80 | 212.1 | 3 min |
| A5 | 1.05 | 278.4 | 3 min |

At each step: adjust needle valve until rotameter reads the target flow ± 1 L/min. Log continuously for the full 3-minute stabilization window plus 1 additional minute of recording. Record the average of all 1-s readings during the recording minute as the `fixture_dp` for that flow. If the SDP810 reads above 480 Pa, stop and use Testo 510 reading only.

### 4.4 Stage A acceptance

- ΔP_fixture increases monotonically with Q.
- SDP810 and Testo 510 agree within ±3 Pa (or ±5%, whichever is larger) at all points.
- If sensors disagree: investigate pressure tube connections; repeat zero check; do not proceed until resolved.

### 4.5 Stage A outputs

A table of `fixture_dp_Pa_at_each_flow` that is entered in the header of every subsequent Stage B, C, D session file.

---

## 5. Stage B — 26 mm Bed

### 5.1 Target

Measure ΔP_total at five velocity points for a 26 mm settled bed of OVC 4×8. Three independently repacked replicates.

### 5.2 Media preparation (each replicate independently)

1. Dry OVC 4×8 in oven at 105°C for minimum 2 hours. Cool to room temperature in desiccator.
2. Weigh media to 0.01 g. Target mass for 26 mm bed: approximately 51 g (at estimated bulk density 450 kg/m³); actual value depends on lot measurement. Record exact weighed mass.
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

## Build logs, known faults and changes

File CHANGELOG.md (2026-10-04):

# Changelog

This file records repository-level changes. Detailed engineering evidence remains in the relevant phase document and result record.

## Unreleased

- 2026-10-05: Added human scale and adjustable room/ceiling/assumed-CADR/time/particle-reduction controls with an ideal decay chart and conditional airflow feasibility limit;19 synthetic JS checks. Refreshed stakeholder/technical reports to8/46 pages and workbooks with validated scenario formulas. Included existing offline recorder and exploratory decay analysis/tests/templates in technical bundle. No measured CADR, room rating, new CFD or mechanical/electrical release.

- 2026-10-05: Added two shareable review bundles: 7-page plain-language stakeholder report/funding workbook and 45-page technical report/review workbook with preserved IH02 engineering payload. Imported actual R03M CAD into Blender, rendered assembly/exploded/cutaway views and two annotated GIFs, and built an offline Simple/Technical 3D viewer. Added source provenance, byte manifests and GitHub coverage exclusions. No native CAD change, new CFD, physical result or construction release.

- 2026-10-05: Reorganized README around the current IH02/R03M prototype, added existing assembly and exploded-view images with limitations, corrected onboarding paths and historical revision wording, and added a local link/tracking check plus a Linux CI template for current analysis tools. Workflow activation is pending credentials with workflow write permission; the template is not an active check. No engineering result or release status changed.

- 2026-10-05: Published the IH02 internal review handoff with stakeholder/engineering PDFs, current R03M CAD and15 DXFs, parts/funding/release registers and corrected analysis tools. Added the current ZIP download exception and byte-preserving handoff attributes; local inspection renders stay ignored. Five current-filter screen tests pass; airflow23, guard28 and control14/1024 checks reproduce. Engineering release and physical performance remain open.

- Added `docs/paper/`: IEEE A4 conference paper draft (DOCX and PDF) with five figures, a team handbook page describing the four-layer architecture, dependencies and tech stack, and `REFERENCES.md` listing paper citations, archived source documents and external sources. Zipped review packages under `reports/` are now ignored because their contents are already tracked as folders. No engineering results changed.

- Package1 R03M mechanical batch:493-object integrated/exploded CAD,119,805 pair checks,joined-guard fabrication route,full proposed cabinet/fan/M5 stacks,positive feet and seal stops. Current panel/guard drawings,fastener schedule and assembly/inspection package. Actual materials/strength/seal/guarding and package2 interface holds remain open.

- Consolidated current D01 handoff:10 panel drawings extracted from saved R02G BRep,245-object inventory, whole-assembly29,116-pair audit, new conditional pressure budget with8 checks,15-page PDF and hash-verified ZIP. Three explicit OPEN mechanical/electrical/performance gates; no build release or physical results.

- R02G independently retained inner/outer fan guards:245-object integrated CAD,8,641 changed-part collision checks and16 assumed tool-envelope checks clear. Revised bracket/skirt/plate details, hardware delta BOM and two-sheet PDF. R02H preserved; no physical/safety release.

- R02H: full proposed adapter nut/washer stacks and ledge screw heads;229-object integrated assembly,13,644 changed-part pair checks clear, both200 mm filter service sweeps clear. Native/STEP verified, R02 preserved. Added drawing sheet, hardware BOM and source-linked evidence; no fabrication/electrical release.

- R02 experimental filter adapter integrated into saved R01 cabinet:169 objects,5,310 new-part pairs clear, native/STEP checks pass, source preserved. Added sealing feedthrough envelopes, positive supports, reducing/retaining panels, two drawing sheets/DXFs and deltaBOM. New filter/reducer invalidates old airflow estimates; not fabrication/electrical/public-use release.

- User-directed internet-only sourcing: official domestic replacement-filter alternatives, import price/dimension discrepancies, CEC primary testing archive and two-page inspected interface comparison. Five arithmetic checks pass. Corrected unsent inquiry gasket dimensions against saved R01 CAD; no supplier contact assigned to user, no CAD modification or purchase.

- D01 filter closure: bounded manufacturer research, archived AAF brochure, identified non-fitting India-listed alternative and prepared unsent exact-duty inquiry. Added supplier-curve checker with ten passing synthetic tests and no extrapolation/purchase release. Missing supplier data remains explicit; no CAD change or external message.

- Added India deployment basis for user-requested heat, public misuse, weather, size and site constraints. Five reproducible deployment checks: heat-limit mismatch, cylinder packaging, additional weather-loss sensitivity and explicitly hypothetical tipping arithmetic. D01 kept indoor-only; no outdoor CAD/product-safety release or procurement.

- D01 component evidence: archived numeric OEM fan curve, reproduced historical R01 and compared six operating scenarios; nine arithmetic checks passed. Added filter headroom table, two-page inspected PDF, primary-source filter candidate and provenance hashes. Both fan SKU-label and curve discrepancies remain unresolved; no new CAD branch, procurement, physical result or safety release.

- D01 R01: detailed integrated guard/cabinet/shelf attachments and cable-routing reservation;163 valid objects,12,675 modeled pair checks clear. Preserved R00 native hash. Revised guard solid-rim pressure budget359.2/337.1/297.5m3/h under unmeasured assumptions, conditional bracket arithmetic, five drawing sheets and11 revised drilling DXFs. Materials/strength/seals/procurement/restart protection unresolved; not released for construction or energization.

- 2026-10-03: Delivered D01 custom indoor demonstrator engineering proposal: integrated/native and exploded CAD, STEP, dimensioned PDF/eight panel-outline DXFs, pressure screening with nine checks,18-line BOM and physical test route. Corrected nominal mechanical interferences and weak retainer edge layout;435 body and1280 fastener pairs clear. OEM product evidence and CC0 public build precedent separated from assumptions. Procurement, detailed guard/joints and restart safety unresolved; no physical build or release claimed. Historical tower files preserved.

- 2026-10-03: Delivered stakeholder-facing six-page prototype PDF and offline clickable explainer, reproducible PDF builder and presentation script. Original diagrams and existing project screenshot; primary online precedent/appliance references clearly separated from our results. Visual/interaction/mobile QA completed; no physical prototype, copied OEM CAD, purchase or new simulation claimed.

- 2026-10-03: Clarified physical-build critical path, three pre-construction release gates and conditional 4–8-week coordination allowance, with unknown external delays excluded. No actual dates booked, supplier messages, procurement, hardware work or gate closure.

- 2026-10-03: Added fan selection brief and fourteen-item unreplied supplier worksheet. Recomputed three-flow clean/loaded scenarios using existing M04 inputs and reran ten tests. No new model assumptions, supplier contact, selected fan, price, physical result or procurement release.

- 2026-10-03: Added preliminary core operating/fault plan, functional electrical SVG and eleven-interface register. Prepared fifteen unexecuted commissioning cases; no rated wiring, terminal assignments, controller implementation, physical validation or release.

- 2026-10-03: Corrected delivery basis to college/NGO funding only and optional/unconfirmed ENTC review while assistant retains digital preparation. Added no-lab buy/rent/paid-service route, ten-item quote scope and reviewer handout; updated active equipment/BOM/gate plans. No purchase, service engagement, fabrication or physical release.

- 2026-10-03: Added OEM-backed borrow-first indoor instrument kit, source PDF archives/hashes, conceptual tap/room mapping and eight-item equipment request CSV. Updated monitoring BOM; duplicate address routing and actual range/calibration approval remain open. No equipment purchased or connected.

- 2026-10-03: Added exploratory indoor single-pair log-decay tool, explicit-window/assumption template and eight synthetic tests. No physical results, uncertainty claims, outdoor estimate or certification; no hardware/control changes.

- 2026-10-03: Added offline measurement importer, traceable metadata template and eight synthetic tests; rejects invalid data/duplicates and refuses output overwrite. No dependencies installed, live sensors/control, physical data or performance claims.

- 2026-10-03: Prepared M05 closure option/request package, load/tolerance and acceptance worksheet, and twelve-item supplier/reviewer response CSV. Inputs remain UNKNOWN; no supplier message, selection, CAD alteration, purchase or release.

- 2026-10-02: Archived/reviewed OEM latch and gasket PDFs; added M05 cutout/preload/tolerance screening with six unit tests. Identified non-drop-in hardware and unresolved closing-force data. No selected hardware, CAD changes, purchase or fabrication release.

- 2026-10-02: Added 48-solid M05 removable HEPA hatch/casing comparison, flange/gasket/cover and generic latch/handle locations, removal audits, visual layout and six regression checks. Earlier CAD unchanged; actual mechanisms, compression, retention and strength not approved.

- 2026-10-02: Added grouped read-only CAD mass inventory, same-geometry hybrid-density comparison, assumed service-tolerance and flat panel/casing corner calculations with six tests. Existing CAD unchanged; no material/gauge/dimension approval or purchases.

- 2026-10-02: Added 36-solid independent inner-housing/continuous-frame fit option, branch inputs/generator/audit and six regression checks. Recorded tight service margins and increased unoptimized all-steel partial weight; earlier CAD preserved. Added six-gate remaining-work checklist, without fabricated percentage or schedule.

- 2026-10-02: Added read-only above-plate material inventory and six-test reaction/alignment/nominal-pressure sensitivity; documented missing loads, contact-loss example and connection review. Segmented frame remains unselected; recommended comparing independent sealed inner housing with continuous supports. No structural approval or CAD changes.

- 2026-10-02: Added segmented capped-post M02/M03 option and combined 41-solid fit CAD/STEP; verified zero checked nominal clashes and sixteen cap/plate contacts without changing original plates. Added interface illustration and six regression checks; structural load transfer and installed sealing remain unapproved.

- 2026-10-02: Added separate twenty-solid M02 frame-routing CAD, STEP, thirteen-reference fit audit, visual layout and mounting-interface register. Recorded eight post/plate clashes and hollow-post bypass risk; no bulkhead changes, structural sizing, base/anchor release or purchases.

- 2026-10-02: Added read-only CAD material-volume inventory, steel/aluminium mass sensitivities, six-test static-moment calculator and M02 support/service/stability review. Identified heavy casing/plate assumptions; excluded solid allowance boxes. Existing CAD unchanged; no structural or fabrication release.

- 2026-10-02: Added standalone M04 hollow transition/outlet study, explicit static/total pressure accounting, component loss sensitivity and installed-effect review gaps; preserved earlier CAD and qualified prior fan estimates.
- 2026-10-02: Added OEM-sourced fan comparison, clean/loaded hardware sensitivity calculations, generated fan-system plot and R02 candidate-envelope option; no fan selected or ordered.
- 2026-10-02: Added R01 intake/cassette interface CAD, lifted service checks, intake/retention screening and draft OEM release questions; preserved R00; fan identity unresolved.
- 2026-10-02: Generated preliminary spreadsheet-driven cylindrical packaging FreeCAD/STEP model, fit audit, source JSON and viewing macro; no fabrication release or changes to historical CAD.
- 2026-10-02: Added preliminary R00 visual layout, airflow/pressure-tap and electrical/control schematics with packaging register and explicit release gaps.
- 2026-10-02: Added preliminary physical-build planning package, tower-specific BOM, reproducible sizing/sensitivity calculator and stakeholder brief; updated onboarding/status. Identified CAD/filter packaging mismatch and pressure-margin limitations. No procurement, final fabrication CAD or new CFD performed.

## 2026-09-16 - GitHub repository initialization

- Added a concise onboarding README with project status, tools, repository map, setup instructions, contribution workflow, safety boundaries, and README maintenance rules.
- Preserved the previous detailed README as `docs/PROJECT_HISTORY.md`.
- Added a Git ignore policy that keeps reproducible source files and curated results while excluding generated CFD fields, meshes, logs, temporary files, videos, dependencies, and build output.
- Added line-ending rules so shell scripts and engineering source files remain compatible with Ubuntu/WSL.
- Added a pull-request checklist requiring contributors to update the README or state why it is unaffected.

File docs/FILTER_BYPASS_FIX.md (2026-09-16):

# Filter Bypass Fix — AQI Tower Phase 10B

**PHASE 10B — BYPASS SEALED AND VERIFIED**  
**CASE_M_SEALED — 5000 iterations — GEO_C geometry — KVO 250 fan curve**  
**SIMULATION — PARTIAL NON-CONVERGED (same RANS oscillatory limit as all prior cases)**

Last updated: 2026-09-06 (Phase 10B).

---

## What Was Fixed

Phase 10A identified that 45% of system airflow (in CASE_M) bypassed the HEPA filter through an unintended open connection at the dirty-plenum/clean-riser junction (z = 0.850 m, x = 0.260–0.305 m). This document records the fix, verification, and updated operating point.

---

## The Bypass Path (Phase 10A Summary)

The GEO_C geometry creates an overlap zone at z = 0.850 m:

| Region | X range | Z range | Note |
|---|---|---|---|
| INTERSTAGE_02 (dirty) | 0.250–0.290 m | < 0.850 m | dirty-side horizontal duct |
| STAGE_03 dirty side | 0.290–0.305 m | < 0.850 m | dirty side of filter mount |
| CLEAN_RISER | 0.260–0.690 m | > 0.850 m | vertical riser, inner wall at x = 0.260 m |

In the overlap zone x = 0.260–0.305 m, dirty-plenum cells (z < 0.850 m) faced CLEAN_RISER cells (z > 0.850 m) through open internal mesh faces at z = 0.850 m. No wall or baffle existed at this interface. The filter at x = 0.305 m was correctly implemented and had no gaps.

**Bypass path:** dirty plenum (x = 0.260–0.305, z < 0.850) → open horizontal face at z = 0.850 → CLEAN_RISER (x = 0.260–0.305, z > 0.850), bypassing the filter entirely.

---

## The Fix

A `bypassSeal` wall baffle was added to `system/createBafflesDict` using the OpenFOAM `plate` surface type:

```
origin (0.260 0.150 0.850)
span   (0.045 0.500 0.0)
```

This creates two wall patches (`BYPASS_SEAL_DIRTY` and `BYPASS_SEAL_CLEAN`) covering the 75 internal faces at the z = 0.850 m interface in the overlap zone. The baffle is a horizontal plate identical in concept to the sheet-metal cap that would seal this gap in physical fabrication.

### What was NOT changed

- Filter resistance, fan curve, turbulence model, solver settings — unchanged
- CASE_M is preserved unmodified
- CASE_M_SEALED is a new directory, created from CASE_M by `scripts/simulation/prepare_case_m_sealed.py`
- blockMeshDict — unchanged; same 67,838-cell mesh
- The porous-baffle relaxation is 0.005 from the start (CASE_M required a multi-phase restart; CASE_M_SEALED starts tight)

### Implementation details

| Item | Value |
|---|---|
| Case source | `cfd/FILTER_H13/CASE_M` (copied, not modified) |
| Case destination | `cfd/FILTER_H13/CASE_M_SEALED` |
| Baffle type | `plate` (OpenFOAM createBaffles surface type) |
| Plate origin | (0.260, 0.150, 0.850) m |
| Plate span | (0.045, 0.500, 0.0) m |
| Plate area | 0.045 × 0.500 = 0.0225 m² |
| Faces converted | 75 (BYPASS_SEAL_DIRTY + BYPASS_SEAL_CLEAN) |
| Filter faces | 961 (unchanged, FILTER_UPSTREAM + FILTER_DOWNSTREAM) |
| porous-baffle relaxation | 0.005 (from iteration 1) |
| endTime | 5000 |

---

## CFD Run: CASE_M_SEALED

### Pre-run checks

| Step | Result |
|---|---|
| blockMesh | OK — 67,838 cells, identical mesh to CASE_M |
| checkMesh | OK — max non-orthogonality 0°, max skewness 3×10⁻¹³ |
| createBaffles | OK — 961 filter + 260 frame + 75 bypass-seal faces converted |

### Solver run

- Solver: `foamRun`, `incompressibleFluid`, steady RANS SIMPLEC, k-epsilon
- Fan curve: KVO 250 6-point codedFixedValue BC at AIR_OUTLET (unchanged)
- Convergence: PARTIAL NON-CONVERGED (same oscillatory RANS limit as all prior GEO_C cases)
- endTime reached: 5000 iterations

---

## Results: Before vs After

| Quantity | CASE_M (unsealed) | CASE_M_SEALED | Change |
|---|---:|---|---|
| Total Q (m³/h) | 1412 | **1332** | −80 m³/h (−5.7%) |
| Q through filter (m³/h) | 776 | **1332** | +557 m³/h (+72%) |
| Bypass fraction | **45.1%** | **~0% (1×10⁻⁹)** | −45 ppt |
| Mean filter face velocity (m/s) | 0.613 | **1.053** | +0.44 m/s (+72%) |
| Filter ΔP (Pa) | 64.7 | **111.2** | +46.5 Pa (+72%) |
| Fan operating head (Pa) | 60.9 | **~115** | +54 Pa (+89%) |
| Fan op. head × filter area CoV | 0.100 | **0.100** | unchanged |

Fan head for CASE_M_SEALED estimated from KVO 250 curve at Q = 1332 m³/h: interpolated between (1200 m³/h, 205 Pa) and (1501 m³/h, 0 Pa) → ~115 Pa.

**Target verification: PASS — bypass fraction < 2% (actual: ~0%).**

### Model self-consistency check (CASE_M_SEALED)

| Check | Value |
|---|---|
| D × μ × v × L = 20,097,755 × 1.8×10⁻⁵ × 1.053 × 0.292 | 111.2 Pa |
| Measured filter ΔP (FILTER_UPSTREAM − FILTER_DOWNSTREAM) × ρ | 111.2 Pa |
| Agreement | ✓ |

Filter velocity CoV = 0.100 (unchanged from CASE_M) — the uniform velocity distribution across the filter face is preserved after sealing.

---

## Convergence Note

All GEO_C cases (Phases 7–10) reach the same oscillatory RANS limit at the 90° turn from horizontal duct to vertical riser. Residuals do not reach the convergence tolerances (p < 1×10⁻⁵, U/k/ε < 1×10⁻⁶) but integrated quantities (Q, filter ΔP, fan head) are stable to better than 1% over the final 500 iterations. Results are classified PARTIAL NON-CONVERGED throughout this project.

---

## Figures Generated (Phase 10B)

| File | Contents |
|---|---|
| `results/FILTER_H13/filter_face_bypass_CASE_M_SEALED.png` | Filter face velocity distribution, sealed case |
| `results/FILTER_H13/bypass_streamlines_CASE_M_SEALED.png` | Streamlines at y ≈ 0.4 m mid-plane, sealed case |
| `results/FILTER_H13/bypass_before_after_CASE_M.png` | Side-by-side: CASE_M vs CASE_M_SEALED — filter face velocities + residual histories |
| `results/FILTER_H13/bypass_analysis_sealed.json` | Machine-readable sealed bypass data + comparison with CASE_M |

Generated by `scripts/simulation/phase10b_visualize.py`.

---

## What Is Still Unknown

1. **CADR estimate remains unavailable.** CASE_M_SEALED gives the corrected filter face velocity, but CADR requires: filter efficiency curve vs particle size (not available beyond H13 ≥ 99.95% for ≥ 0.3 µm), actual loaded-filter resistance, and a realistic particle source model.

2. **Physical fabrication gap.** In a real device, sealing the bypass requires a sheet-metal cap or gasket between the filter mounting frame (x = 0.305 m) and the inner riser wall (x = 0.260 m) at z = 0.850 m. This structural detail is not yet in the CAD model.

3. **CASE_L_SEALED / CASE_H_SEALED.** Only CASE_M was re-run with the seal. The sealed operating point for the L and H resistance scenarios is not yet computed. Given that the bypass path is fully blocked, the sealed L/H results will converge to Q_total / FILTER_AREA ≈ similar face velocities to the sealed CASE_M, scaled by the fan curve response.

4. **Non-convergence root cause.** The oscillatory RANS limit at the 90° turn has not been resolved. This would require geometry smoothing (curved transition) or a different turbulence model. Out of scope for Phase 10B.

---

## Recommended Next Step

**Phase 11 — Post-processing and CADR framework.**

With the bypass sealed, CASE_M_SEALED provides a corrected airflow field. The next priorities are:

1. Obtain a full filter efficiency curve for the Freudenberg SF13-B at the operating face velocity.
2. Estimate a preliminary CADR from the corrected filter flow rate and the ≥ 99.95% H13 efficiency.
3. Evaluate prefilter (G4/M5) addition for loaded-filter lifetime extension, if a particulate loading model is pursued.
4. Add the bypass seal geometry to the FreeCAD model for fabrication documentation.

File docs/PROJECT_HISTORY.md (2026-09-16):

# AQI Tower

AQI Tower is a student-led project to develop and computationally investigate a tower-type air-purification system before any physical fabrication. The working concept is a vertical machine with driven airflow, multiple filtration stages, biomass-derived adsorption, and eventual sensing and monitoring. These are hypotheses to investigate, not a final design.

**Phase 18 engineering decision:** The initially proposed water-spray stage has been evaluated and rejected on technical grounds (NO-GO). It is replaced by a G4/M5 washable panel pre-filter. See `docs/PHASE18_WATER_SPRAY_FEASIBILITY.md` and `docs/PHASE18_WATER_SPRAY_DECISION_MATRIX.md`.

## Current Project Phase

**PHASE 19 COMPLETE — G4/M5 PRE-FILTER SPECIFICATION — RFQ REQUIRED BEFORE FINAL PRODUCT FREEZE.**
**PHASE 18 COMPLETE — WATER-SPRAY STAGE FEASIBILITY — DECISION: NO-GO.**
**PHASE 17B — PROCUREMENT UNBLOCK — RFQ READY — NO ITEMS ORDERED YET.**
**PHASE 17A EXPERIMENT: BLOCKED — HARDWARE NOT YET AVAILABLE.**
**GAS-PHASE CFD: BLOCKED — NO MEASURED INPUTS YET. HCHO TESTING: DEFERRED (requires institutional safety approval).**

Phase 19 converted the Phase 18 G4/M5 recommendation into a technical specification, procurement package, and pressure-drop analysis. No experiment was performed. No CFD was run. No CAD was changed. No existing results were modified.

Phase 18 evaluated whether the proposed water-spray stage is technically justified. The decision is NO-GO. The stage is replaced by a G4/M5 washable panel pre-filter. No experiment was performed. No CFD was run. No CAD was changed. No existing results were modified.

Phase 17B researches and documents actionable procurement routes for all Phase 17A hardware blockers. No items have been ordered.

Phase 17A produces no fake data. Fabricating experimental results is explicitly prohibited.

### Phase 18 record

**PHASE 18 COMPLETE — WATER-SPRAY STAGE FEASIBILITY — DECISION: NO-GO — DATE: 2026-09-07.**

Phase 18 is a research-only engineering go/no-go review of the proposed water-spray pre-treatment stage. No CFD was run, no CAD was changed, no existing results were modified.

Key Phase 18 findings:

- **PM2.5 irrelevant:** Simple spray cannot capture PM2.5. The Greenfield gap (0.1–2 µm) means inertial impaction and diffusion are both ineffective at this scale and energy input. Expected efficiency < 3% for 0.3–2.5 µm particles.
- **Hygiene risk is disqualifying:** Recirculating warm water with aerosol generation (Legionella, biofilm, mold) in a device delivering air to a breathing zone violates the device's fundamental purpose. ASHRAE 188 and CIBSE TM13 requirements are not feasible for a student prototype.
- **Coarse function fully replaced:** The only defensible function — coarse pre-collection — is achieved more safely and efficiently by a dry G4/M5 washable panel pre-filter.
- **Pressure drop penalty:** 35–125 Pa additional resistance reduces airflow by 7–23% on an already constrained KVO 250 fan.
- **HCHO removal negligible:** < 0.1% per pass at project concentrations. Not a substitute for the activated carbon stage.
- **Complexity unjustified:** 12+ additional components for zero unique, irreplaceable function.
- **Decision matrix:** Option B (G4/M5 pre-filter) scores 84/100; Option A (water spray) scores 13/100. The 71-point gap is insensitive to weighting changes.
- **Recommended treatment sequence:** Inlet → [G4/M5 washable pre-filter] → [Activated carbon bed] → [H13 HEPA] → Clean riser → KVO 250 fan → Outlet
- **CFD unchanged:** GEO_C and CASE_M_SEALED remain valid; pre-filter ΔP can be added analytically when the product is selected.

See [docs/PHASE18_WATER_SPRAY_FEASIBILITY.md](docs/PHASE18_WATER_SPRAY_FEASIBILITY.md) and [docs/PHASE18_WATER_SPRAY_DECISION_MATRIX.md](docs/PHASE18_WATER_SPRAY_DECISION_MATRIX.md).

### Phase 19 record

**PHASE 19 COMPLETE — G4/M5 PRE-FILTER SPECIFICATION AND INTEGRATION — DATE: 2026-09-07.**

Phase 19 converted the Phase 18 recommendation into a technically defensible, procurable, mechanically integrable pre-filter stage. No CFD run, no CAD change, no experiment.

Key Phase 19 outputs:

- **Selected class:** G4 (EN 779:2012 / ISO Coarse ≥ 60%). Sufficient HEPA protection at lower ΔP than M5; M5 available as upgrade from same supplier.
- **Selected size:** 592 × 592 × 48 mm (matches HEPA footprint; face velocity 1.06 m/s = HEPA face velocity).
- **Clean ΔP estimate:** ~21–30 Pa at 1.06 m/s [engineering estimate — RFQ required for confirmed value].
- **System impact (clean G4):** Q drops from 1332 to ~1300 m³/h (~2.4% reduction from baseline). Remaining fan margin for carbon bed: ~57–67 Pa.
- **Maintenance trigger:** 80 Pa ΔP across pre-filter (SDP810-500Pa sensor, upstream/downstream static taps).
- **Integration:** slide-in cassette at inlet face; EPDM gasket seal; snap retention; no tools required.
- **Preferred supplier:** Freudenberg India (existing Phase 12A contact) + simultaneous backup RFQ to Camfil India.
- **Procurement status:** RFQ REQUIRED — T-01 (filter panel × 2), T-02 (cassette frame), T-04 (tower DP sensor).
- **CFD rerun:** NOT REQUIRED (< 3% flow change; within RANS uncertainty; analytical fan-curve intersection is adequate).

See [docs/PHASE19_PREFILTER_SPECIFICATION.md](docs/PHASE19_PREFILTER_SPECIFICATION.md), [docs/PHASE19_PREFILTER_DECISION_MATRIX.md](docs/PHASE19_PREFILTER_DECISION_MATRIX.md), and updated [docs/PRESSURE_DROP_BUDGET.md](docs/PRESSURE_DROP_BUDGET.md).

Phase 17B outputs (procurement unblock):

- **OVC 4×8 media:** Three verified India contact routes — (1) Kuraray India kuraray.com/in-en/contact-us/, (2) Kuraray Environmental Solutions carbon-solutions.kuraray.com, (3) Chemet India info@chemetindia.com +91 22 6680 2222 (confirmed Calgon Carbon distributor). Jacobi Carbons India (infoin@jacobi.net) identified as fallback non-OVC source. Price: REQUIRES QUOTE from all routes.
- **SDP810-500Pa:** Confirmed listing at Tanotis India; price **₹4,748.73 incl. taxes** (2026-09-07); "Add to cart" available.
- **Rotameter A (0–100 L/min):** Confirmed at Shree Aashapura Mumbai IndiaMART; price **₹1,950** (2026-09-07).
- **Testo 510:** Confirmed IndiaMART listings **₹9,999–₹12,197** (two India vendors, 2026-09-07); borrow from physics/civil lab first.
- **Acrylic column:** Requires custom 75 mm ID order (standard 75 mm OD ≈ 69 mm ID — wrong); fabrication spec in tracker; cost REQUIRES QUOTE (~₹600–1,500 tube + ₹1,000–3,000 machining).
- **FORMASORB:** Same Kuraray/Chemet routes as OVC 4×8; classified BUY LATER / QUOTE NOW; RFQ letter ready in PHASE17B_OVC4X8_RFQ.md.
- **Ready-to-send RFQ letters:** Two letters (OVC 4×8 and FORMASORB) in `docs/PHASE17B_OVC4X8_RFQ.md`; one alternative letter for Jacobi India if OVC 4×8 is unavailable.
- **Column fabrication spec:** Full dimensioned specification (75 mm ID, 300 mm length, machined end caps, O-ring grooves, pressure taps, screen seats, bed-depth scale, HCHO limitation notice) in `docs/PHASE17B_PROCUREMENT_TRACKER.md` Section 4.
- **Full tracker:** 17 P0 items, 3 P1 items, 7 P2 items, 8 P3 items with status, price, and next action in `docs/PHASE17B_PROCUREMENT_TRACKER.md`.
- **Verified buy-now minimum:** ₹6,698.73 confirmed (SDP810 + Rotameter A); total P0 estimated ~₹11,153 + media quote + column/machining quote.
- **Primary blocker:** OVC 4×8 lot availability and price — must be resolved before any other procurement decision is final.

See [docs/PHASE17B_PROCUREMENT_TRACKER.md](docs/PHASE17B_PROCUREMENT_TRACKER.md) and [docs/PHASE17B_OVC4X8_RFQ.md](docs/PHASE17B_OVC4X8_RFQ.md).

### Prior Phase 17A record (hardware blocked — planning complete)

Phase 17A planning outputs:

- **Pre-experiment checklist:** 17 items; all PENDING (hardware not in hand).
- **Instrument record template:** ready to complete on procurement.
- **Data template:** `results/PRESSURE_DROP_PHASE17A/RAW_DATA_TEMPLATE.csv` — correct headers; no data rows.
- **Analysis script:** `scripts/analysis/phase17a_analysis.py` — full Python pipeline; reads RAW_DATA.csv; applies validity flags; computes fixture-corrected ΔP; fits Darcy–Forchheimer (a and b) with non-negativity constraint; reports R², residuals, 95% CI; generates three figures; writes `DARCY_FORCHHEIMER_FIT.json`; handles empty-CSV gracefully.
- **Analysis method:** `results/PRESSURE_DROP_PHASE17A/PRESSURE_DROP_ANALYSIS.md` — validity categories (VALID / VALID_FLAGGED / INVALID), Stage A–D procedure, Darcy–Forchheimer fitting, OpenFOAM translation formulae.
- **Fit JSON template:** `results/PRESSURE_DROP_PHASE17A/DARCY_FORCHHEIMER_FIT_TEMPLATE.json` — schema with all nulls; overwritten by script when data are available.
- **Results document:** `docs/PHASE17A_PRESSURE_DROP_RESULTS.md` — full acceptance criteria, QC table, OpenFOAM translation table, all values NOT MEASURED, final decision table.
- **No fake data.** All ΔP fields, coefficients, and R² values are null or NOT MEASURED until physical experiment is performed.

See [docs/PHASE17A_PRESSURE_DROP_RESULTS.md](docs/PHASE17A_PRESSURE_DROP_RESULTS.md).

### Prior Phase 16 record

**PHASE 16 COMPLETE — PROCUREMENT-READY CLEAN-AIR PRESSURE-DROP SYSTEM.**

Phase 16 converted the Phase 15 engineering specification into a procurement-ready, build-ready clean-air pressure-drop test system. No experiment was performed. No CFD was run. No CAD was changed. HCHO testing is deferred to Phase 17B+.

Key Phase 16 outputs:

- **Phase 15 calculations independently audited:** all values confirmed correct; one rounding difference of 0.14 L/min at 0.80 m/s (not significant); new finding: Ergun estimate ~586 Pa at 104 mm bed, 1.05 m/s (marginally exceeds 500 Pa primary sensor range; backup wide-range instrument added).
- **Instruments selected:** Sensirion SDP810-500Pa (primary DP, I²C, 1 Pa resolution); Testo 510 0–10,000 Pa (secondary/check); Rotameter A 0–100 L/min ₹1,950 (baseline conditions); Rotameter B 0–300 L/min REQUIRES QUOTE (high-velocity conditions); SHT40 breakout T/RH sensor; Sensirion SHT40 ×2.
- **Column material decision:** acrylic 75 mm ID for Phase 16 clean-air only; SS316 or borosilicate glass required when HCHO breakthrough testing begins (Phase 17B+).
- **Rig flow schematic defined:** vertical column, bottom-to-top flow, pressure taps at each end, rotameter downstream (clean side).
- **Clean-air data schema defined:** 14 mandatory fields; post-processing only for corrected ΔP and Darcy–Forchheimer coefficients.
- **Test matrix defined:** Stage A (empty rig baseline) + Stages B/C/D (26/52/104 mm beds), five velocity points each, three independently repacked replicates per depth.
- **Stop criteria, QC thresholds, and replicate rejection criteria defined.**
- **Darcy–Forchheimer fitting procedure specified:** from measurements only; no invented or literature coefficients.
- **Procurement tables:** BUY NOW (clean-air items, ~₹11,550 Tier 1 minimum / ~₹35,000 Tier 2 recommended); BUY LATER (HCHO items — not until Phase 17B approval); OUTSOURCE (column machining, external HPLC).
- **Build order: 15 numbered steps** with per-step acceptance checks.
- **Critical procurement blockers:** OVC 4×8 India availability and lot quote; column machining lead time; SDP810 India stock confirmation; Rotameter B quote.

See [docs/PHASE16_INSTRUMENT_SELECTION.md](docs/PHASE16_INSTRUMENT_SELECTION.md), [docs/PHASE16_PROCUREMENT_PLAN.md](docs/PHASE16_PROCUREMENT_PLAN.md), and [docs/PHASE16_CLEAN_AIR_TEST_PROTOCOL.md](docs/PHASE16_CLEAN_AIR_TEST_PROTOCOL.md).

### Prior Phase 15 record

**PHASE 15 COMPLETE — TEST-RIG ENGINEERING SPECIFICATION.**

Phase 15 converted the Phase 14 experimental requirements into a buildable, procurement-ready engineering package for the packed-bed bench test. No experiment was performed. No CFD was run. No CAD was changed.

Key Phase 15 outputs:

- **Column diameter selected:** 75 mm ID recommended (wall-effect ratio 15.8×; flows 35–278 L/min across the full Phase 14 velocity matrix). 50 mm is the minimum viable alternative.
- **Column and flow matrix tabulated:** exact Q (L/min), EBCT (s), and bed volume (mL) for all Phase 14 combinations of U_s (0.13–1.05 m/s) and bed depth (26, 52, 104 mm).
- **SFA30 documentation verified:** current v1.3 datasheet (January 2025) confirmed. ±20 ppb accuracy floor means the SFA30 cannot alone validate C/C0 ≤ 0.10 at the 50 µg/m³ inlet. DNPH–HPLC reference method is mandatory.
- **DNPH / HPLC workflow defined:** ISO 16000-3:2022 cartridge sampling with outsourced analysis; institutional laboratory collaboration recommended before purchasing cartridges.
- **HCHO generation specification:** Architecture A (certified gas cylinder + two calibrated MFCs + static mixer + exhaust scrubber) defined as the recommended approach. All cylinder/MFC items require quotes; institutional safety approval required before any purchase.
- **Pressure and flow measurement architectures defined:** 0–500 Pa DP sensor (≤1 Pa resolution), rotameter for pressure-drop tests, MFC for breakthrough tests.
- **Media containment, sealing, sampling ports, transport-delay, and safety boundary all defined.**
- **Synchronized data schema and Raspberry Pi CSV logger architecture defined.**
- **BOM produced:** all items classified (VERIFIED PRODUCT / CANDIDATE PRODUCT / GENERIC REQUIREMENT / REQUIRES QUOTE / UNKNOWN); cost tiers established.
- **Critical procurement blockers identified:** institutional safety approval, OVC 4×8 / FORMASORB India availability, certified HCHO cylinder, MFCs, and external HPLC laboratory.

See [docs/PHASE15_TEST_RIG_ENGINEERING_SPEC.md](docs/PHASE15_TEST_RIG_ENGINEERING_SPEC.md), [docs/PHASE15_BOM.md](docs/PHASE15_BOM.md), and [docs/PHASE15_DATA_ACQUISITION_SPEC.md](docs/PHASE15_DATA_ACQUISITION_SPEC.md).

### Prior Phase 14 record

**PHASE 14 COMPLETE — FORMALDEHYDE GAS-PHASE TARGET FROZEN.**

Phase 14 independently compared formaldehyde, benzene, toluene, acetone, ethanol, and generic TVOC. Formaldehyde ranked first in the documented weighted decision matrix and is now the single target gas for the carbon-stage research program.

Key Phase 14 decisions:

- **Target gas:** formaldehyde, HCHO / CH₂O, CAS 50-00-0.
- **Baseline challenge:** 100 µg/m³ (about 81.3 ppb at 25 °C and 1 atm); comparison points 50 and 200 µg/m³.
- **Baseline environment:** 25 ± 2 °C and 50 ± 5% RH; high-humidity stresses are defined separately.
- **Primary breakthrough metric:** `t10`, the elapsed time and treated bed volumes to sustained, time-aligned `C/C0 ≥ 0.10`, confirmed by a reference method.
- **Material decision B:** Calgon Carbon OVC 4×8 remains the non-impregnated research control, while a traceable formaldehyde-specific impregnated carbon such as FORMASORB is the secondary comparison.
- **Measurement:** synchronized upstream/downstream dedicated HCHO sensors for the continuous curve, with DNPH–HPLC as the concentration reference. The low-cost sensors are not sufficient alone for early low-outlet validation.
- **Safety:** intentional HCHO generation is restricted to a closed, exhausted, institutionally approved laboratory system. No improvised hotplate, formalin, polymer, furniture, or occupied-room challenge is permitted.
- **No performance claim:** no formaldehyde removal efficiency, adsorption capacity, breakthrough time, bed life, gas CADR, or porous-media coefficient has been measured.

See [docs/PHASE14_FORMALDEHYDE_TARGET.md](docs/PHASE14_FORMALDEHYDE_TARGET.md).

### Prior Phase 13 record

Phase 13 defined the proposed carbon stage as a gas-phase adsorption stage rather than a generic AQI or particulate filter. It selected Calgon Carbon OVC 4×8 as a primary research candidate before the gas target was known, documented FORMASORB as a conditional HCHO specialist, and recorded the missing pressure and adsorption data. Phase 14 supersedes only the earlier **TARGET GAS — NOT YET DEFINED** status; the Phase 13 evidence limitations remain in force.

See [docs/BIOCHAR_MATERIAL_SELECTION.md](docs/BIOCHAR_MATERIAL_SELECTION.md), [docs/BIOCHAR_EXPERIMENT_PLAN.md](docs/BIOCHAR_EXPERIMENT_PLAN.md), and [docs/BIOCHAR_CFD_PLAN.md](docs/BIOCHAR_CFD_PLAN.md).

### Prior Phase 12B record

**PHASE 12B COMPLETE — CONSERVATIVE PARTICLE TRACKING.**

Phase 12B tracked four assumed particle sizes through the frozen `CASE_M_SEALED` timestep-5000 velocity field. The airflow CFD, geometry, fan, bypass seal, and HEPA pressure-drop model were not changed or rerun.

Key Phase 12B findings:
- **FILTER ARRIVAL FRACTION:** 62.1% for 0.3, 1, and 2.5 µm; 61.2% for 10 µm.
- **WALL DEPOSITION FRACTION:** 37.9% for 0.3, 1, and 2.5 µm; 38.8% for 10 µm. These totals include both filter-frame contacts and other wall contacts; the source results retain those subcategories.
- **OUTLET ESCAPE FRACTION:** 0% in the conservative terminal accounting. This is a result of the sealed flow topology and the upstream filter-arrival gate, not proof of particle capture.
- **Particle accounting:** exact for every size (224 injected = filter arrival + wall deposition + outlet escape + other).
- **Model scope:** one-way, dilute equilibrium-slip paths with gravity; nearest-neighbour velocity lookup and first-order Euler stepping. The figures show airflow streamlines and tracked particle terminal positions, not stored full particle path histories.
- **FILTER ARRIVAL ≠ FILTER CAPTURE.** No filter capture probability was applied. Product-specific η(d_p) remains unavailable, so no filtration-efficiency, PM2.5-removal, CADR, or AQI-reduction claim is made.

See [docs/PARTICLE_CFD_V12B.md](docs/PARTICLE_CFD_V12B.md) and [results/PARTICLE_CFD/PARTICLE_TRACKING_RESULTS.md](results/PARTICLE_CFD/PARTICLE_TRACKING_RESULTS.md).

### Prior Phase 12A record

**Phase 12A — Freudenberg technical data acquisition — COMPLETE.**

Phase 12A searched all available public sources for fractional efficiency, MPPS, and multi-point pressure-drop data for the Freudenberg SF13-B-0593x0593x292 H13 HEPA filter. No CFD was run or modified.

Key Phase 12A findings:
- **Fractional efficiency curve η(d_p): NOT PUBLICLY AVAILABLE.** No efficiency vs particle size data found in any public source, including manufacturer product pages, downloads centre, or product catalog.
- **MPPS particle diameter: NOT AVAILABLE** as product-specific data. Generic glass fibre range is 0.1–0.25 µm (literature).
- **Multi-point ΔP curve: NOT AVAILABLE.** Only the single rated point (300 Pa at 2.84 m/s) is publicly listed.
- **ISO 29463 class confirmed: ISO 35 H** (equivalent to H13 EN 1822). New data point from Freudenberg US product page.
- **EN 1822 test certificate confirmed to accompany each unit.** This certificate contains the actual fractional efficiency data and MPPS — it must be obtained on purchase.
- **Freudenberg India contact established:** Pune HQ +91 20 67633600, email info@freudenberg-filter.com. Draft data request letter written.

See [docs/FREUDENBERG_DATA_REQUEST.md](docs/FREUDENBERG_DATA_REQUEST.md), [docs/FREUDENBERG_DATA_GAPS.md](docs/FREUDENBERG_DATA_GAPS.md).

### Prior Phase 11 record

**Phase 11 — HEPA efficiency evidence audit + CADR methodology — COMPLETE.**

Phase 11 audited all available HEPA filtration-efficiency information, defined a rigorous CADR methodology, and planned the future particle CFD study. No CFD was run or modified.

Key Phase 11 findings:
- **H13 classification confirmed** (EN 1822, ≥99.95% at MPPS) from Freudenberg product page. This is the only confirmed efficiency data point.
- **Particle-size-specific efficiency data: NOT AVAILABLE** for this product. No efficiency curve, no MPPS value, no data at PM2.5 or PM10 sizes.
- **Efficiency at AQI Tower face velocity (1.05 m/s): NOT AVAILABLE.** The EN 1822 test is at 2.84 m/s.
- **FINAL CADR = NOT ESTABLISHED.** A conditional theoretical estimate (~1331 m³/h at MPPS) is defined but explicitly labelled THEORETICAL / CONDITIONAL — NOT MEASURED.
- **CADR claim hierarchy (Levels 0–4)** defined in `docs/CADR_METHODOLOGY.md`. Current position: Level 0–1.
- **Future particle CFD plan** defined in `docs/PARTICLE_CFD_PLAN.md`. Not yet run.

See [docs/CADR_METHODOLOGY.md](docs/CADR_METHODOLOGY.md), [data/filters/HEPA_EFFICIENCY_EVIDENCE.md](data/filters/HEPA_EFFICIENCY_EVIDENCE.md), [docs/PARTICLE_CFD_PLAN.md](docs/PARTICLE_CFD_PLAN.md).

### Prior Phase 10B record

**Phase 10B — HEPA H13 filter bypass sealed — COMPLETE.**

Phase 10A diagnosed the 38–48% filter bypass (Phase 9) as an unintended open connection at z = 0.850 m between the dirty plenum and the CLEAN_RISER (x = 0.260–0.305 m overlap zone). Phase 10B sealed this gap with a wall baffle and reran CASE_M. Bypass dropped from 45% to ~0%. The corrected operating point is **Q ≈ 1332 m³/h, fan head ≈ 115 Pa, filter ΔP = 111 Pa** — much closer to the Phase 6D analytical budget (Q ≈ 1300 m³/h, ΔP ≈ 133 Pa). CADR estimation is now gated only by filter efficiency data (not yet available). See [results/FILTER_H13_COMPARISON.md](results/FILTER_H13_COMPARISON.md) and [docs/FILTER_BYPASS_FIX.md](docs/FILTER_BYPASS_FIX.md).

### Prior Phase 9 record

**Phase 9 — HEPA H13 filter resistance CFD — PARTIAL COMPLETE — FILTER BYPASS DISCOVERED.**

Three sensitivity cases (CASE_L / CASE_M / CASE_H) were run on the GEO_C tower geometry with a porous-baffle representation of the Freudenberg SF13-B H13 HEPA filter, driven by the KVO 250 6-point fan curve. The filter model is calibrated to the single available manufacturer data point (300 Pa at 2.84 m/s, clean). All three cases ran 5000 iterations; all are PARTIAL — NON-CONVERGED (same RANS limit as V00/GEO_C); integrated quantities are stable.

Key Phase 9 findings:
- **H13 filter is the dominant system resistance.** Fan operating head increases 13–19× from the empty-tower baseline (3.50 → 45–68 Pa) for CASE_L → CASE_H. Airflow drops only 4–6% (1496 → 1402–1435 m³/h) because the KVO 250 operates on a flat fan curve near free delivery.
- **Filter bypass discovered: 38–48% of airflow bypasses the filter face.** Bypass fraction increases with filter resistance — a physically real flow path around the filter. Effective filtration fraction: 52–62% of total Q. Resolved in Phase 10B. See [FILTER_H13_COMPARISON.md](results/FILTER_H13_COMPARISON.md).
- **Porous-baffle relaxation = 0.005 required** for stable filter ΔP behaviour. Default (0.2) produced oscillatory filter ΔP per iteration. This setting must be preserved for all future filter-stage CFD.
- **CFD result vs. budget:** CFD gives Q ≈ 1412 m³/h at 61 Pa (CASE_M unsealed), compared to the Phase 6D analytical estimate of Q ≈ 1300 m³/h at 133 Pa. The difference was primarily driven by the bypass path reducing effective system resistance.

See [results/FILTER_H13_COMPARISON.md](results/FILTER_H13_COMPARISON.md) and [docs/FILTER_H13_MODEL.md](docs/FILTER_H13_MODEL.md).

### Prior Phase 8 record

**Phase 8 — Airflow geometry optimization — COMPLETE.**

Three new parametric empty-tower geometries were tested with the unchanged six-point KVO 250 terminal-suction model and comparable 20 mm all-hexahedral meshes. GEO_C is the **PROMISING / BEST CURRENT GEOMETRY**: it converged in 926 iterations and a fresh confirmation reproduced the result exactly. Relative to V01, GEO_C reduces simulated empty-path total-pressure loss from 17.33 to 3.50 Pa, peak speed from 6.53 to 5.62 m/s, full-riser reverse-flow indicator from 23.12% to 15.88%, and riser-entry CoV from 1.087 to 0.234.

GEO_A is **PROMISING BUT UNCERTAIN** because its improved airflow field remains non-converged. GEO_B is **REJECTED** because recirculation/low-speed metrics worsen despite convergence. See [Phase 8 comparison](results/GEOMETRY_OPTIMIZATION_COMPARISON.md) and [setup/diagnosis](docs/GEOMETRY_OPTIMIZATION.md). V00 and V01 are preserved. No filters, particles, water, solar, or final product geometry were added.

### Prior Phase 6D record

Phase 5 (V00, empty tower, placeholder 1 m/s inlet) is complete at the PARTIAL — NON-CONVERGED level. The best V00 solution (SIMPLEC, iteration 6000) showed ~33 Pa empty-tower pressure drop at Q = 1,512 m³/h.

Phase 6B conducted real manufacturer research on five fan candidates. Phase 6C verified three manufacturer PDFs directly and obtained the first real HEPA H13 filter data point. Phase 6D extracted a full numeric fan curve for the KVO 250 from the PDF using PyMuPDF vector path extraction. Key findings:

- **G2E140 thermal-limit claim corrected (Phase 6C):** The "50 Pa maximum back pressure" from Phase 6B was a misinterpretation. The manufacturer document specifies a MINIMUM test back pressure (not a maximum operating limit). The G2E140 cannot be rejected on thermal grounds; remains Tier 3 pending performance datasheet.
- **Systemair KVO 250 — Evidence A — 6-point fan curve — CFD READY (Phase 6D):** Manufacturer catalog confirmed (Phase 6C). All specs confirmed. Fan curve: 2 confirmed numeric + 4 graph-digitized points via PyMuPDF Bezier extraction. **Shutoff head CORRECTED: ~688 Pa ±20 Pa** (Phase 6C rough estimate was ~850 Pa — outside the stated uncertainty range). CFD STATUS: CFD READY WITH GRAPH-DIGITIZATION UNCERTAINTY.
- **First filter data (Phase 6C):** Freudenberg SF13-B H13 HEPA, 593×593×292 mm, 300 Pa initial ΔP at 2.84 m/s. Single point only.
- **Preliminary operating estimate (KVO 250 + one clean HEPA):** Q ≈ 1300 m³/h at ΔP ≈ 133 Pa — rough orientation figure, unchanged by Phase 6D shutoff correction (operating point lies in confirmed curve region).
- **V01_fan placeholder is archived.** Phase 7 used a terminal suction boundary with the actual curve; no baffle or CAD change was needed.
- **No final fan selected.** The empty-tower numerical operating point is available; the final purifier operating point remains unknown.

See [docs/FAN_SELECTION.md](docs/FAN_SELECTION.md), [docs/FAN_DATA_GAPS.md](docs/FAN_DATA_GAPS.md), [docs/FAN_CURVE_AUDIT.md](docs/FAN_CURVE_AUDIT.md), and [docs/PRESSURE_DROP_BUDGET.md](docs/PRESSURE_DROP_BUDGET.md).

## Repository Purpose

The repository is intended to keep the work reproducible and understandable for a student team with computer science and biotechnology backgrounds. Engineering decisions should be documented in accessible language and progressively validated instead of treating the current concept as correct.

## Current Software Status

Last updated: 2026-09-07 (Phase 17B procurement unblock complete — RFQ letters ready; OVC 4×8 routes identified; SDP810 and Rotameter A prices confirmed; column fabrication spec written; no CFD, CAD change, or experiment performed).

- **DETECTED:** Windows 11, FreeCAD 1.1.3, Python, Git, Node.js, npm, WSL 2 with Ubuntu, Visual Studio Code, CMake, GCC, and Clang.
- **INSTALLED (Phase 5):** OpenFOAM Foundation 14 (Ubuntu package), ParaView 5.11.2 with python3-paraview — both in WSL Ubuntu.
- **NOT INSTALLED:** CfdOF workbench, Three.js project package.
- **FACT:** FreeCAD was installed on `D:` with explicit approval during Phase 4.

See [docs/ENVIRONMENT.md](docs/ENVIRONMENT.md) for detected versions and hardware details.

## Repository Layout

| Location | Current content |
| --- | --- |
| `docs/` | Environment, project overview, CAD V00, CFD V00 documentation |
| `requirements/` | Engineering requirements, requirements matrix, assumptions |
| `cad/parametric/` | `AQI_Tower_ConceptA_V00.FCStd` — parametric FreeCAD model (Phase 4) |
| `cfd/V00/` | OpenFOAM case: mesh, boundary conditions, all timestep fields (0–9000), solver logs |
| `scripts/simulation/` | `run_cfd_v00.sh`, `run_cfd_v00_continue.sh`, `analyze_cfd_v00.py` |
| `results/CFD_V00/` | `metrics.json`, `residuals.csv`, `residual_history.png`, `velocity_streamlines.png`, `pressure_section.png` |
| `results/CFD_V00_RESULTS.md` | Full V00 CFD results record |
| `results/CFD_V01_FAN_RESULTS.md` | Actual KVO 250 result, partial convergence, pressure definitions and comparison |
| `results/CFD_V01_FAN/` | Five figures, final metrics, residual history and independent verification |
| `cfd/V01_fan/` | Real KVO 250 curve-driven case; final fields at iteration 4000; archived placeholder |
| `cad/parametric/AQI_Tower_ConceptA_GEO_A/B/C.FCStd` | Native parametric Phase 8 design experiments; all dimensions labelled as non-requirements |
| `cfd/GEO_A/`, `cfd/GEO_B/`, `cfd/GEO_C/` | Three empty-tower geometry trials using the unchanged KVO 250 model |
| `cfd/GEO_C_CONFIRM/` | One fresh, identical GEO_C confirmation run |
| `results/GEOMETRY_OPTIMIZATION_COMPARISON.md` | Phase 8 results, pressure/airflow/recirculation comparison, classifications, and filter-readiness gate |
| `results/GEOMETRY_OPTIMIZATION/` | Actual metrics, field/residual figures, baseline diagnosis, comparison data, and verification |
| `docs/GEOMETRY_OPTIMIZATION.md` | Pre-run diagnosis, hypotheses, controlled trial plan, actual outcome, and reproduction workflow |
| `docs/FAN_SELECTION.md` | Fan comparison table, architecture options, Phase 6B/6C candidate assessments |
| `docs/FAN_DATA_GAPS.md` | Gap analysis, scenario analysis, next-action priority list (Phase 6C) |
| `docs/FAN_CURVE_AUDIT.md` | Per-candidate fan curve source, points, uncertainty, CFD readiness audit |
| `docs/PRESSURE_DROP_BUDGET.md` | System resistance framework; first filter data; preliminary operating point |
| `data/fans/README.md` | Minimum datasheet requirements; current candidate status |
| `data/fans/*.json` | Structured fan data records (5 candidates, updated Phase 6C) |
| `data/filters/README.md` | Minimum filter datasheet requirements |
| `data/filters/freudenberg_SF13B_593x593x292.json` | HEPA H13 filter data (Freudenberg, Phase 6C); Phase 12A: ISO 29463 class, India contacts, gap summary added |
| `docs/FREUDENBERG_DATA_REQUEST.md` | Phase 12A: data status, all sources searched, contact routes, draft inquiry letter for fractional efficiency data |
| `docs/FREUDENBERG_DATA_GAPS.md` | Phase 12A: gap impact table, CADR level readiness, particle CFD readiness, recommended actions |
| `scripts/simulation/run_cfd_v01_fan.sh` | Run script for V01_fan |
| `cfd/FILTER_H13/CASE_L/`, `CASE_M/`, `CASE_H/` | Phase 9 HEPA H13 porous-baffle cases; 5000-iteration runs; filter_implementation.json per case |
| `results/FILTER_H13_COMPARISON.md` | Phase 9 primary results: fan operating point, filter ΔP, bypass fraction, impact classification |
| `docs/FILTER_H13_MODEL.md` | Filter model methodology, Darcy derivation, bypass finding, convergence notes |
| `results/FILTER_H13/` | Phase 10A/10B visualizations: velocity/pressure slice, filter face maps, bypass streamlines, residual histories, 3-case comparison, before/after bypass figures, bypass_analysis.json, bypass_analysis_sealed.json |
| `docs/FILTER_BYPASS_DIAGNOSIS.md` | Phase 10A bypass diagnosis: geometric mechanism, evidence, per-case data, confidence, recommended fix |
| `docs/FILTER_BYPASS_FIX.md` | Phase 10B: fix implementation (bypassSeal baffle), verification (bypass~0%), updated operating point |
| `cfd/FILTER_H13/CASE_M_SEALED/` | Phase 10B bypass-sealed case; 5000-iteration run; all timesteps |
| `scripts/simulation/phase10a_visualize.py` | pvpython script that generated all Phase 10A figures |
| `scripts/simulation/prepare_case_m_sealed.py` | Pure Python: copies CASE_M and adds bypassSeal baffle to createBafflesDict |
| `scripts/simulation/phase10b_visualize.py` | pvpython script: generates Phase 10B before/after figures and bypass_analysis_sealed.json |
| `data/filters/HEPA_EFFICIENCY_EVIDENCE.md` | Phase 11: full evidence audit — H13 confirmed, particle-size data NOT AVAILABLE, CADR not established |
| `docs/CADR_METHODOLOGY.md` | Phase 11: CADR concept, claim hierarchy (Levels 0–4), system factors, conditional theoretical estimate |
| `docs/PARTICLE_CFD_PLAN.md` | Phase 11: Lagrangian particle CFD plan — scope, inputs required, open questions, sequence |
| `docs/PARTICLE_CFD_V12B.md` | Phase 12B: audited particle model, exact accounting, interpretation, limitations, and future η(d_p) hook |
| `scripts/simulation/phase12b_particle_tracking.py` | Phase 12B equilibrium-slip particle path integration and technical figure generator |
| `results/PARTICLE_CFD/` | Phase 12B machine-readable results, audited results record, four endpoint/streamline figures, and summary figure |
| `data/filters/biochar_candidates.json` | Phase 13 machine-readable candidate properties, evidence, gaps, and research selection |
| `docs/BIOCHAR_MATERIAL_SELECTION.md` | Phase 13 material distinctions, candidate comparison, adsorption evidence, pressure-loss evidence, and selection |
| `docs/BIOCHAR_EXPERIMENT_PLAN.md` | Future pressure-drop, adsorption, breakthrough, and humidity bench-test plan; no experiment performed |
| `docs/BIOCHAR_CFD_PLAN.md` | Future measured-data-driven porous-media framework; no coefficients and no CFD case created |
| `docs/PHASE14_FORMALDEHYDE_TARGET.md` | Frozen HCHO target, weighted pollutant selection, concentration/EBCT/measurement/safety requirements, material decision, experiments, and CFD data gates |
| `docs/PHASE15_TEST_RIG_ENGINEERING_SPEC.md` | Phase 15: column geometry analysis, diameter selection (75 mm), flow/EBCT/bed-volume tables, media containment, pressure and flow measurement, HCHO generation requirements, SFA30 current documentation, DNPH/HPLC workflow, sealing, safety boundary, acceptance criteria |
| `docs/PHASE15_BOM.md` | Phase 15: full procurement table by category; VERIFIED / CANDIDATE / GENERIC / REQUIRES QUOTE / UNKNOWN classification; three cost tiers; critical procurement blockers |
| `docs/PHASE15_DATA_ACQUISITION_SPEC.md` | Phase 15: synchronized data schema, Raspberry Pi CSV logger architecture, calibration requirements, C/C0 post-processing procedure, DNPH chain-of-custody record |
| `docs/PHASE16_INSTRUMENT_SELECTION.md` | Phase 16: Phase 15 calculation audit, column material selection, DP/flow/T-RH instrument selection, tubing/fittings/screens, ASCII flow schematic, clean-air data schema, acceptance criteria |
| `docs/PHASE16_PROCUREMENT_PLAN.md` | Phase 16: BUY NOW / BUY LATER / OUTSOURCE tables with India prices; three budget tiers (₹11,550 / ₹35,000 / ₹65,000); 15-step build order; procurement timeline |
| `docs/PHASE16_CLEAN_AIR_TEST_PROTOCOL.md` | Phase 16: Stage A–D test procedure, velocity sequence, pre-test checklist, replicate protocol, stop criteria, QC thresholds, Darcy–Forchheimer fitting procedure, data retention |
| `docs/PHASE17A_PRESSURE_DROP_RESULTS.md` | Phase 17A: BLOCKED status; pre-conditions checklist; NOT MEASURED data tables; OpenFOAM translation table; acceptance criteria; resume instructions |
| `docs/PHASE17B_OVC4X8_RFQ.md` | Phase 17B: ready-to-send RFQ letters for OVC 4×8 (Routes 1–4) and FORMASORB; what to record on receipt |
| `docs/PHASE17B_PROCUREMENT_TRACKER.md` | Phase 17B: full item tracker (17 P0, 3 P1, 7 P2, 8 P3 items); verified India prices; column fabrication spec (75 mm ID acrylic, end caps, O-rings, taps) |
| `results/PRESSURE_DROP_PHASE17A/RAW_DATA_TEMPLATE.csv` | Phase 17A: header-only CSV template; all data fields present; no measurement rows |
| `results/PRESSURE_DROP_PHASE17A/PRESSURE_DROP_ANALYSIS.md` | Phase 17A: data validity rules (VALID/FLAGGED/INVALID), fixture correction procedure, Darcy–Forchheimer fitting steps, Ergun comparison rules, OpenFOAM translation formulae |
| `results/PRESSURE_DROP_PHASE17A/DARCY_FORCHHEIMER_FIT_TEMPLATE.json` | Phase 17A: coefficient output schema; all values null; overwritten by analysis script on experiment completion |
| `scripts/analysis/phase17a_analysis.py` | Phase 17A: full Python analysis pipeline — validity flags, fixture correction, replicate statistics, Darcy–Forchheimer fit, plots, JSON output |
| `memory/project_status.md` | Concise current project state for future continuation |
| `reports/` | CAD preview and figure QA notes |
| `threejs/` | Not yet populated |

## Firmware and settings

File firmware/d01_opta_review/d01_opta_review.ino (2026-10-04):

// BENCH REVIEW ONLY. Default configuration never closes any relay.
// Do not use this sketch to control fans or implement protective functions.
#include <Arduino.h>
#include <initializer_list>
#include "ControlLogic.h"

#ifndef AQI_BENCH_LAMP_OUTPUT_ENABLED
#define AQI_BENCH_LAMP_OUTPUT_ENABLED 0
#endif

ControlLogic control;
Debounce startButton, resetButton;
uint32_t lastScan=0;
bool scanInitialized=false;

void setup() {
  // OEM mapping: output1=D0 ... output4=D3; I1=A0 ... I5=A4.
  for (int relay : {D0,D1,D2,D3}) {
    digitalWrite(relay,LOW);
    pinMode(relay,OUTPUT);
  }
  for (int input : {A0,A1,A2,A3,A4}) pinMode(input,INPUT);
  for (int led : {LED_D0,LED_D1,LED_D2,LED_D3}) {
    digitalWrite(led,LOW); pinMode(led,OUTPUT);
  }
  // No networking, retained RUN bit, USB start command or wait for Serial.
}

void loop() {
  const uint32_t now=millis();
  const uint32_t elapsed=uint32_t(now-lastScan);
  if (scanInitialized && elapsed<5) return;
  // A returned long scan inhibits operation; this does not protect a frozen CPU.
  const bool scanFault=scanInitialized && elapsed>100;
  scanInitialized=true; lastScan=now;
  const bool start=startButton.update(digitalRead(A0)==HIGH,now);
  const bool stopHealthy=digitalRead(A1)==HIGH; // bench NC STOP loop
  const bool reset=resetButton.update(digitalRead(A2)==HIGH,now);
  const bool benchPermit=digitalRead(A3)==HIGH;
  const bool sourcePresent=digitalRead(A4)==HIGH; // DIGITAL, never analogRead
  const bool request=control.step(sourcePresent,benchPermit&&!scanFault,start,!stopHealthy,reset);
  digitalWrite(LED_D0,request?HIGH:LOW); // RUN REQUESTED, not fan-running proof
  digitalWrite(LED_D1,control.trip?HIGH:LOW);
  digitalWrite(LED_D2,sourcePresent?HIGH:LOW); // not proof of isolation
  digitalWrite(LED_D3,LOW);
  // Enabling this is only for a reviewed, fused low-voltage dummy-lamp bench.
  digitalWrite(D0,(AQI_BENCH_LAMP_OUTPUT_ENABLED && request)?HIGH:LOW);
  digitalWrite(D1,LOW); digitalWrite(D2,LOW); digitalWrite(D3,LOW);
}

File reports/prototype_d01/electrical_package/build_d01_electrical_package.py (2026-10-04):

"""Generate the bounded D01 E00 electrical review, not fabrication wiring."""
from pathlib import Path
import csv, hashlib, importlib.util, json, zipfile
from reportlab.pdfgen import canvas
from reportlab.lib.colors import HexColor
from reportlab.platypus import Paragraph
from reportlab.lib.styles import ParagraphStyle
ROOT = Path(__file__).resolve().parents[2]
OUT = ROOT/'reports/prototype_d01/electrical_package'
OUT.mkdir(parents=True, exist_ok=True)
spec = importlib.util.spec_from_file_location('control', ROOT/'scripts/analysis/d01_control_acceptance.py')
import sys
control = importlib.util.module_from_spec(spec); sys.modules['control'] = control; spec.loader.exec_module(control)
checks = control.tests()
sources = [
 ('S1','ARCTIC P14 Max black','https://www.arctic.de/en/P14-Max-Black/ACFAN00287A'),
 ('S2','NV-PS1 specifications','https://www.noctua.at/en/products/nv-ps1/specifications'),
 ('S3','NA-FC1 specifications','https://www.noctua.at/en/products/na-fc1/specifications'),
 ('S4','NA-FH1 specifications','https://www.noctua.at/en/products/na-fh1/specifications'),
 ('S5','NA-FH1 manual','https://cdn.noctua.at/media/noctua_na_fh1_manual_spot_en.pdf?download=true'),
 ('S6','NV-PS1 manual','https://cdn.noctua.at/media/noctua_nv_ps1_manual_en_web.pdf?download=true'),
 ('S7','NA-FH1 features','https://www.noctua.at/en/products/na-fh1/features')]
budget = {'basis':'Nominal arithmetic, not measured startup or coordinated protection',
 'voltage_V':12, 'fan_count':4, 'fan_current_A':0.35,
 'fan_total_A':4*0.35, 'fan_total_W':12*4*0.35,
 'supply_limit_A':2, 'hub_input_limit_W':24,
 'nominal_difference_A':2-4*0.35, 'auxiliary_load_A':'UNKNOWN',
 'startup_sensitivity':[{'assumed_multiplier':k,'fan_only_A':1.4*k,
 'difference_to_2A':2-1.4*k} for k in (1,1.25,1.5,2)],
 'voltage_drop_example':{'assumptions':'Copper rho 0.0175 ohm mm2/m at reference temperature; 1 m one-way; 0.5 mm2; 1.4 A. NOT cable selection.',
 'drop_V':2*1*0.0175/0.5*1.4}}
assert abs(budget['fan_total_W']-16.8)<1e-9
assert abs(budget['nominal_difference_A']-.6)<1e-9
assert abs(budget['voltage_drop_example']['drop_V']-.098)<1e-9
checks['arithmetic_checks']=3
def js(name, data): (OUT/name).write_text(json.dumps(data,indent=2),encoding='utf-8')
js('checks.json',checks); js('power_budget.json',budget)
js('sources.json',{'accessed':'2026-10-04','sources':[dict(zip(('id','title','url'),s)) for s in sources],
 'scope':'Manufacturer descriptions only; no India stock, price, whole-device compliance or delivered-unit verification claimed.'})
interfaces = [
 ['J01','Site outlet -> NV-PS1','OEM mains plug','Site socket / upstream protection / India conformity unresolved; no bare-mains modification'],
 ['J02','NV-PS1 -> NA-AC10','OEM barrel connection','5.5 / 2.1 mm; use supplied keyed adapter, do not infer polarity from size'],
 ['J03','NA-AC10 -> NA-FC1 input','OEM 4-pin connection','Review reference chain; protective switching insertion not yet selected'],
 ['J04','NA-FC1 output -> NA-FH1 input','OEM 4-pin / NA-EC1','24 W path limit; no SATA supply'],
 ['J05-08','NA-FH1 ports 1-4 -> fans F1-F4','OEM keyed 4-pin','One fan per port; four independent labels; exact cable routing and extensions unresolved'],
 ['J09','Protective module -> fan power permission','UNSELECTED','DC load breaking, latched inhibit, monitored recovery and failure response require rated design'],
 ['J10','Logger -> instruments only','Separate domain','No USB connection to hub / fan power; no GPIO safety or fan supply'],
 ['J11','Service isolation -> all energy sources','UNSELECTED','Prevent reconnection; stopped impeller / dark lamp not proof of isolation']]
bom = [
 ['F1-F4','4','ARCTIC P14 Max black ACFAN00287A','REFERENCE','12 V / 0.35 A each; exact delivered revision still verify; S1'],
 ['PS1','1','Noctua NV-PS1 incl. NA-AC10','REFERENCE','12 V / 2 A / 24 W; external Class II adapter; S2/S6'],
 ['SC1','1','Noctua NA-FC1','REFERENCE','3 A / 36 W maximum; NOT protective stop; S3'],
 ['H1','1','Noctua NA-FH1 incl. NA-EC1','REFERENCE','24 W on selected input; self-resetting fuse; S4/S5'],
 ['PR1','1 assembly','Independent protective control and isolation','UNSELECTED','Not replaced by PWM controller, hobby relay or this Python model'],
 ['CB1','1','Insulating / protected low-voltage enclosure','UNSELECTED','140 x 100 x 40 CAD reservation only; mount and ventilation to resolve'],
 ['W1','as needed','OEM compatible extensions / strain relief','UNSELECTED','Length, temperature, voltage drop, retention and guard entry required'],
 ['PB','set','START / STOP / RESET and indicators','UNSELECTED','Ratings and protective architecture must be selected together']]
def csvout(name, header, rows):
    with (OUT/name).open('w',newline='',encoding='utf-8') as f:
        w=csv.writer(f);w.writerow(header);w.writerows(rows)
csvout('INTERFACES.csv',['ID','Endpoints','Connection','Release limitation'],interfaces)
csvout('BOM.csv',['ID','Quantity','Item','Status','Basis'],bom)
c=canvas.Canvas(str(OUT/'AQI_D01_ELECTRICAL_REVIEW.pdf'),pagesize=(595,842))
c.setTitle('AQI D01 - Electrical and controls review E00')
style=ParagraphStyle('body',fontName='Helvetica',fontSize=11,leading=16,textColor=HexColor('#203747'))
page=0;y=0
def para(text):
    global y
    p=Paragraph(text,style);w,h=p.wrap(503,700)
    assert y-h>62, (page,text[:50],y,h)
    p.drawOn(c,46,y-h);y-=h+13
def new(title,subtitle):
    global page,y
    if page:c.showPage()
    page+=1
    c.setFillColor(HexColor('#102d3c'));c.rect(0,726,595,116,fill=1,stroke=0)
    c.setFillColor(HexColor('#70dec5'));c.setFont('Helvetica-Bold',10);c.drawString(46,801,'AQI TOWER / D01 / E00 / 04 OCT 2026')
    c.setFillColor(HexColor('#ffffff'));c.setFont('Helvetica-Bold',21);c.drawString(46,765,title)
    c.setFillColor(HexColor('#203747'));c.setFont('Helvetica',10);c.drawString(46,706,subtitle)
    c.setFont('Helvetica-Bold',8);c.drawString(46,32,'REVIEW ONLY - NOT RELEASED FOR WIRING OR ENERGIZING')
    c.drawRightString(548,32,str(page));y=675
new('Powering the first prototype','Package 2: one electrical review for the existing R03M assembly')
para('<b>Decision:</b> retain four 12 V fans and an external OEM power adapter as the reference route. Keep mains wiring outside the cabinet. Use local speed adjustment; no app or custom power PCB is needed for the first experiment.')
para('<b>What this closes:</b> the OEM connection reference, nominal load calculation, named interfaces, enclosure fit screen, restart acceptance model and fault-test specification are now in one reproducible package.')
para('<b>What it does not close:</b> the rated protective stop/restart circuit. The OEM chain can run fans, but does not itself satisfy our manual-restart requirement. It is not an approved wiring diagram.')
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

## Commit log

2026-09-16 Initialize AQI Tower project repository
    [AQI_Tower_ConceptA_GEO_A.FCStd, AQI_Tower_ConceptA_GEO_B.FCStd, AQI_Tower_ConceptA_GEO_C.FCStd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]
2026-10-03 Add D01 build package, packaging studies, measurement tools and paper
    - D01 indoor demonstrator: CAD revisions R00 to R03M, drawings, BOMs,
    pressure screening, component validation and review handoff
    - Full-tower packaging studies M02-M05 (FreeCAD/STEP with fit audits)
    - Build planning documents in docs/build (electrical, fan duty,
    deployment, instrument kit, measurement recording)
    - Analysis, geometry, monitoring and report scripts with unit tests
    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
    [A01_REDUCER.dxf, A01_Reducer_Front.dxf, A01_Reducer_Rear.dxf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]
2026-10-04 Add D01 electrical package, guard access audit, validation package and harness detail
    - D01 electrical package: BOM, interfaces, power budget, protective candidate screen, 7-page PDF review, previews
    - Guard access audit (GUARD_ACCESS_AUDIT.json, GUARD_ACCESS_DECISION.md) and bending sensitivity (GUARD_BENDING_SENSITIVITY.json)
    - Harness detail: routing checks JSON
    - Validation package: pressure budget, blank measurement CSVs, run log, manifest, checks
    - Internal handoff 20261004: stakeholder brief PDF, engineering review PDF, drawings PDF, combined parts register, pressure budget, digital checks
    - OEM cable enquiries doc (docs/build/OEM_CABLE_ENQUIRIES.md)
    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
    [A01_Reducer_Front.dxf, A01_Reducer_Rear.dxf, A04_Retainer_Front.dxf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]
2026-10-04 Publish current IH02 engineering handoff and R03M analysis
    [A01_Reducer_Front.dxf, A01_Reducer_Rear.dxf, A04_Retainer_Front.dxf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]
2026-10-04 Improve prototype onboarding with actual CAD visuals and checks
2026-10-04 Deliver CAD-based stakeholder and technical review bundles
    [A01_Reducer_Front.dxf, A01_Reducer_Rear.dxf, A04_Retainer_Front.dxf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]
2026-10-04 Add person scale and assumption-labelled indoor room sizing model
    [GITHUB_COVERAGE.csv, STAKEHOLDER_FUNDING.xlsx, TECHNICAL_REVIEW.xlsx]
2026-10-04 Keep viewer source and packaged bytes consistent after QA cleanup
    [STAKEHOLDER_FUNDING.xlsx, TECHNICAL_REVIEW.xlsx]
2026-10-04 Correct R03M partial mass from guard perforations and OEM fan weights
    [GITHUB_COVERAGE.csv, STAKEHOLDER_FUNDING.xlsx, TECHNICAL_REVIEW.xlsx]
2026-10-04 Add OEM-based D01 power wiring and coordination review
    [E01_RATED_PARTS.csv, GITHUB_COVERAGE.csv, STAKEHOLDER_FUNDING.xlsx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]
2026-10-04 Implement host-tested D01 ordinary control bench candidate
    [GITHUB_COVERAGE.csv, STAKEHOLDER_FUNDING.xlsx, TECHNICAL_REVIEW.xlsx]
2026-10-04 Separate Opta host tests from Arduino sketch and refresh handoff
    [STAKEHOLDER_FUNDING.xlsx, TECHNICAL_REVIEW.xlsx]
2026-10-04 Verify default D01 firmware against official Opta board toolchain
    [GITHUB_COVERAGE.csv, STAKEHOLDER_FUNDING.xlsx, TECHNICAL_REVIEW.xlsx]
2026-10-04 Add OEM-checked D01 external control module layout and CAD
    [D01_E03_CONTROL_ENVELOPES.FCStd, D01_E03_CONTROL_ENVELOPES.step, GITHUB_COVERAGE.csv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]
2026-10-04 Add E04 lid-control CAD and ordinary input review with fit limits
    [D01_E04_LID_CONTROL_ENVELOPES.FCStd, D01_E04_LID_CONTROL_ENVELOPES.step, GITHUB_COVERAGE.csv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]
2026-10-04 Resolve control service-space conflicts and consolidate current engineering handoff
    [CURRENT_CONTROL_PLACEMENT.csv, CURRENT_RELEASE_GATES.csv, D01_E05_CURRENT_CONTROL_LAYOUT.FCStd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]
2026-10-04 Complete parallel prototype review batch and refresh handoff bundles
    [AUDIT_FINDINGS.csv, CABLE_AND_INTERFACE_SCHEDULE.csv, CURRENT_COMBINED_PARTS_REGISTER.csv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]
